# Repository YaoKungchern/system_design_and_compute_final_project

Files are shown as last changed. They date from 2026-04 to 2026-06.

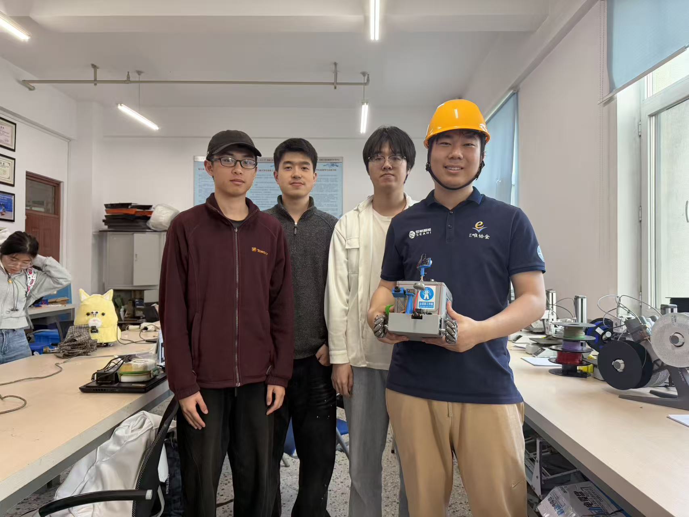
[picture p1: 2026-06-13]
docs/合照.jpg

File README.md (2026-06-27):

# System Design and Compute Final Project — Trace Rover

> 系统设计与计算课程期末项目：基于 STM32H723 的麦克纳姆轮巡逻小车（Trace Rover）下位机控制工程。

本仓库为课程期末项目的源代码与文档归档，核心是一个运行在 **STM32H723VGTx（Cortex‑M7）** 上的嵌入式控制系统，负责小车的电机驱动、PWM 输出、串口通信以及与上位机的交互。整体工程使用 **Keil MDK‑ARM（uVision 5）+ ARMCLANG V6.19** 开发，同时支持 **Embedded IDE (EIDE)** 环境。

---

## 目录结构总览
```shell
system_design_and_compute_final_project/
├── LICENSE                    # 项目开源协议（MIT）
├── README.md                  # 项目说明文档（本文件）
├── .gitignore                 # Git 忽略规则
├── control/                   # 下位机嵌入式控制工程（STM32H723）
│   └── Trace_Rover/           # Keil MDK-ARM 工程根目录
│       ├── .eide/             # Embedded IDE 配置文件（可选）
│       ├── Core/              # 用户核心代码（Inc 头文件 + Src 源码）
│       ├── Drivers/           # HAL 驱动与 CMSIS 头文件
│       │   ├── CMSIS/         # ARM CMSIS 核心与 STM32H7 设备支持包
│       │   └── STM32H7xx_HAL_Driver/ # ST 官方 HAL 库源码
│       ├── MDK-ARM/           # Keil 工程文件、编译产物与调试配置
│       ├── .mxproject         # STM32CubeMX 项目记录
│       └── .clang-format      # C/C++ 代码格式化规则
├── software/                  # 上位机控制软件（PyQt5 + Python 3.11）
│   └── Trace_Rover_GC/        # Qt Creator 工程根目录
│       ├── .qtcreator/        # Qt Creator 工程配置与 Python 虚拟环境
│       ├── main.py            # 程序入口
│       ├── main_widget.py     # 主界面逻辑（配合 main_widget.ui）
│       ├── control_widget.py  # 手动控制面板逻辑
│       ├── pid_widget.py      # PID 参数调参面板逻辑
│       ├── main_func.py       # 主要功能调度
│       ├── trace_rover_comm.py # 与下位机的串口通信协议实现
│       ├── navigation.py      # 导航与路径规划模块
│       ├── mission.py         # 任务编排与执行模块
│       ├── vision.py          # 视觉图像处理模块（图传/识别）
│       ├── control.py         # 控制指令生成模块
│       ├── pid.py             # 上位机 PID 控制器实现
│       ├── config.py          # 全局配置参数
│       ├── utils.py           # 通用工具函数
│       ├── main_widget.ui     # 主界面 UI 设计文件
│       ├── control_widget.ui  # 控制面板 UI 设计文件
│       └── pid_widget.ui      # PID 调参面板 UI 设计文件
├── electronics/               # 硬件工程（嘉立创 EDA）
│   └── ProPrj_TraceRover_2026-03-28.epro2 # 嘉立创工程文件（原理图 + PCB）
├── structure/                 # 机械结构文件（SolidWorks）
│   ├── （模型装配体）.SLDASM   # 整车总装配体
│   ├── 上层装配1.SLDASM       # 上层板/传感器组件装配
│   ├── Board.step.STEP.SLDASM # 主板/PCB 安装支架装配
│   ├── Enter.step.STEP.SLDASM # 外壳/舱门部件装配
│   ├── Next.step.STEP.SLDASM  # 外壳/舱门部件装配
│   ├── J1/J3/J6.step.STEP.SLDASM # 连接器/接口部件装配
│   ├── ZDT_X28_L28Motor.STEP.SLDASM # 步进电机驱动板装配
│   ├── ZDT_X28_V1.2_PCB.step.STEP.SLDASM # 步进电机驱动板 PCB 装配
│   ├── 28_STEPPER_MOTOR.STEP.SLDPRT # 28 步进电机零件模型
│   ├── MC520编码器电机模型-升级款.step.SLDPRT # 带编码器的主驱动电机
│   ├── 80l/80r.SLDPRT         # 左右轮系零件
│   ├── 上层板绘制尝试.SLDPRT  # 上层板结构零件
│   ├── 底盘模型.SLDPRT        # 底盘结构零件
│   ├── 小车底盘壳.SLDPRT      # 底盘外壳零件
│   ├── 上下板连接铜柱.SLDPRT  # 连接件零件
│   ├── 支柱.SLDPRT            # 支撑零件
│   ├── PCB支柱.SLDPRT         # PCB 支撑零件
│   ├── 相机底座.SLDPRT        # 相机安装支架
│   ├── 相机柱.SLDPRT          # 相机支撑柱
│   ├── 相机柱80mm.SLDPRT      # 相机支撑柱（80mm）
│   ├── 电机延长轴.SLDPRT      # 传动零件
│   ├── 电机联轴器.SLDPRT      # 传动零件
│   ├── 滑环轴.SLDPRT          # 导电滑环轴
│   ├── 六角联轴器.step.SLDPRT # 联轴器零件
│   ├── 皮带1-1.SLDPRT         # 同步带零件
│   ├── 皮带线同步带-2.SLDPRT  # 同步带零件
│   ├── HTPA20S5M100_A_P6_35_a - 电机侧.SLDPRT # 同步带轮（电机侧）
│   ├── HTPA20S5M100_A_P6_35_a_导电滑环侧.SLDPRT # 同步带轮（滑环侧）
│   ├── ts-1145a-b-a_White.step.STEP.SLDPRT # 摄像头外壳
│   ├── 外壳终版.SLDPRT        # 最终版外壳外罩
│   ├── 电池.SLDPRT            # 电池盒模型
│   ├── 37电机支架.step.SLDPRT # 37 电机安装支架
│   ├── Sensor Ultrasónico.SLDPRT # 超声波传感器模型
│   ├── 图传发射模块.SLDPRT    # 图传发射模块外罩
│   ├── ZDT_X28_L28Motor.STEP  # 步进电机驱动板 STEP 模型
│   ├── ZDT_X28_V1.2.STEP.SLDPRT # 步进电机驱动板 PCB 模型
│   ├── WIRE_2.0.STEP.SLDPRT   # 线束模型
│   ├── SHIM_2.7x4x6.STEP.SLDPRT # 垫片模型
│   ├── Open CASCADE STEP translator 6.8 1.1.1.step.STEP.SLDPRT # 第三方 STEP 零件
│   ├── MT0522..FL.SLDPRT      # 法兰支架零件
│   ├── BREACKET.SLDPRT        # 通用支架零件
│   ├── PH2.0-WI-4P.step.STEP.SLDASM # PH2.0 连接器装配（4P）
│   ├── PH2.0-WI-8P.step.STEP.SLDASM # PH2.0 连接器装配（8P）
│   ├── PH2.0-WI-4P-0.step.STEP.SLDPRT # PH2.0 连接器单零件（4P）
│   ├── PH2.0-WI-8P-3.step.STEP.SLDPRT # PH2.0 连接器单零件（8P）
│   ├── PH2.0-WI--1.step.STEP.SLDPRT # PH2.0 连接器外壳
│   ├── PH2.0-WI-.step.STEP.SLDPRT # PH2.0 连接器锁片
│   ├── 6308926832.step.STEP.SLDASM # 采购件/标准件装配
│   └── 6308926992.step.STEP.SLDASM # 采购件/标准件装配
└── docs/                      # 项目文档与多媒体文件
    ├── 项目开题报告.pptx      # 开题答辩 PPT
    ├── 项目开题报告.pdf       # 开题报告 PDF
    ├── 项目结题报告.pptx      # 结题答辩 PPT
    ├── 项目结题报告.pdf       # 结题报告 PDF
    ├── 通信数据帧格式.xlsx    # 上下位机通信协议定义
    ├── 讲解视频.mp4           # 系统讲解视频
    ├── 宣传视频.mp4           # 项目宣传视频
    └── 合照.jpg               # 团队/实物合照
```

---

### 1. `docs/` — 项目文档与多媒体

`docs/` 目录是课程提交的核心资料，汇集了从开题到结题的全流程文档与展示素材，按用途可分为四组。

| 组别 | 文件 | 内容与用途 |
| --- | --- | --- |
| **开题阶段** | `项目开题报告.pptx`
`项目开题报告.pdf` | 项目立项资料：选题背景、系统需求分析、总体方案设计（机械结构 / 硬件电路 / 软件架构 / 通信协议）、预期功能与性能指标、时间节点规划。答辩用 PPT 及 PDF 定稿版本。 |
| **结题阶段** | `项目结题报告.pptx`
`项目结题报告.pdf` | 项目结项资料：系统实现细节、关键算法（电机 PID、路径规划、上位机交互）、测试与实验结果、性能分析、问题与改进总结。答辩用 PPT 及 PDF 定稿版本。 |
| **通信协议** | `通信数据帧格式.xlsx` | **上位机‑下位机通信的数据帧规范文档**。定义了帧头、设备地址、功能码、数据域、校验和（异或校验）、帧尾等字段的字节排列、大小端、单位与取值范围；同时列出了小车运行、停止、速度调节、转向、状态回传等命令码。是两端软件联调的契约文件。 |
| **展示素材** | `讲解视频.mp4` | 功能讲解视频：对系统整体方案、硬件组成、软件流程、现场演示进行讲解，用于课程答辩与成果展示。 |
| | `宣传视频.mp4` | 项目宣传视频：展示小车外观、运行效果与亮点功能，用于课程作业展示、宣传或评奖材料。 |
| | `合照.jpg` | 项目团队合照 / 小车实物合照，作为结题资料存档。 |

> **重点提示**：
> - `通信数据帧格式.xlsx` 是软件开发人员的首要参考文档，定义了上位机与下位机之间的字节级通信契约。
> - `项目结题报告.pdf` / `.pptx` 是对整个项目架构、实现与测试最完整的文字化总结，建议作为阅读代码前的前置资料。
> - 两份视频分别面向"功能讲解"与"成果宣传"两种场景，按需观看。

---

## 各文件夹及文件功能详解

### 2. `control/Trace_Rover/` — 下位机控制工程（STM32H723）

这是项目的核心工程目录，对应一辆名为 **Trace Rover** 的履带式巡逻小车的下位机固件。

| 子目录/文件 | 功能说明 |
| --- | --- |
| `.eide/` | Embedded IDE（VS Code 插件）的工程配置：
- `eide.yml`：EIDE 工程主配置
- `env.ini`：构建环境变量
- `files.options.yml`：文件级编译选项
- `trace_rover.st.option.bytes.ini`：STM32 选项字节配置 |
| `.cmsis/` | CMSIS 设备模板，包含 ARM Cortex‑A/M 系列的启动代码、链接脚本与内核头文件，用于多芯片支持 |
| `Core/Inc/` | 用户头文件：`main.h`、`gpio.h`、`tim.h`、`usart.h`、`stm32h7xx_it.h`、`stm32h7xx_hal_conf.h` |
| `Core/Src/` | 用户源代码，详见下方小节 |
| `Drivers/CMSIS/` | ARM CMSIS 核心头文件（`core_cm7.h` 等）、编译器适配层，以及 STM32H7 设备寄存器定义（`stm32h723xx.h`） |
| `Drivers/STM32H7xx_HAL_Driver/` | ST 官方 HAL 库：`Inc/` 提供外设驱动头文件，`Src/` 为对应实现（GPIO、UART、TIM、DMA、RCC、PWR、FLASH、I2C、EXTI 等） |
| `MDK-ARM/` | Keil uVision5 工程：
- `Trace_Rover.uvprojx` / `.uvoptx`：工程与选项文件
- `DebugConfig/*.dbgconf`：调试配置
- `RTE/_Trace_Rover/RTE_Components.h`：运行时组件头文件
- `Trace_Rover/`：编译产物（`.axf`、`.hex`、`.map`、`.htm` 等） |
| `.mxproject` | STM32CubeMX 生成/记录文件，表明工程由 CubeMX 初始化后进行二次开发 |
| `.clang-format` | 统一的代码风格配置文件，便于 CLion / VS Code / Keil 等 IDE 自动格式化 |

> **值得注意的编译产物线索**：从 `MDK-ARM/Trace_Rover/` 下的 `.o` 目标文件可以反向推断出工程中实际存在但未在 `Core/Src/` 目录显式出现的业务模块——`actuator.o`、`comm.o`、`fsm.o`、`filter.o`、`tasks.o`、`time_slice.o`、`ultrasonic.o`、`pid.o`、`coordinate2d.o`、`mecanum.o`、`fifo.o`。这些模块分别实现了执行器控制、通信协议、有限状态机（FSM）、滤波、任务调度、时间片轮转、超声波采集、PID、坐标变换、麦轮运动学解算等核心功能，是整个下位机控制的"真正大脑"。

#### `Core/Src/` 源码解读

| 文件 | 功能 |
| --- | --- |
| `main.c` | **程序入口**。初始化 HAL、配置系统时钟（HSE + PLL，主频 550 MHz 级别）、初始化 GPIO / TIM1/2/3/4/5/8/15 / USART1/2/3，然后调用 `tasks_init()` 并在主循环中执行 `tasks_run()` 进行调度。 |
| `gpio.c` | GPIO 初始化：LED、按键、电机方向控制引脚等 |
| `tim.c` | 定时器初始化：TIM1/TIM8 用于 PWM 驱动电机，TIM2/TIM3/TIM4/TIM5 用于输入捕获或编码器测速，TIM15 用于周期性中断（任务调度/心跳） |
| `usart.c` | 串口初始化：USART1/2/3，分别对应上位机通信、调试串口、外部传感器/模块通信 |
| `stm32h7xx_it.c` | 中断服务例程（HardFault、SysTick、UART、TIM 等） |
| `stm32h7xx_hal_msp.c` | HAL 底层初始化（GPIO 复用、时钟使能、DMA 配置） |
| `system_stm32h7xx.c` | 系统启动文件与向量表相关辅助函数 |

---

### 3. `software/Trace_Rover_GC/` — 上位机控制软件（PySide6 + Python 3.11）

这是运行在 PC 端的上位机图形化控制程序，使用 **Qt Creator** 作为 UI 设计工具，运行在 **Python 3.11** 虚拟环境中。主要功能包括：手动遥控小车、下发运动指令、实时回传并显示小车状态数据、PID 参数在线调参、视觉图像（图传画面）显示与处理、以及按任务序列自动巡航。

#### 核心 Python 源文件

| 文件 | 功能 |
| --- | --- |
| `main.py` | **程序入口**。初始化 QApplication、加载主窗口 `main_widget`、启动事件循环。 |
| `main_widget.py` | 主界面逻辑实现。整合串口状态显示、连接按钮、手动/自动模式切换、小车状态面板、图像显示区、日志窗口等。配合 `main_widget.ui` 共同描述界面布局。 |
| `control_widget.py` | **手动控制面板逻辑**。提供开环、速度闭环与位置闭环再不同坐标系下控制等操作入口，通过 `control.py` 与 `trace_rover_comm.py` 下发指令。 |
| `pid_widget.py` | **PID 参数调参面板**。提供 P/I/D 三系数的输入框、读写按钮、载入与保存参数按钮，通过串口与下位机同步参数。 |
| `main_func.py` | **主功能调度器**。整合 `navigation`、`mission`、`vision`、`control`、`pid` 等模块，在主循环中按帧处理：解析传感器数据 → 更新状态 → 生成控制量 → 下发下位机。 |
| `trace_rover_comm.py` | **串口通信协议核心**。按照 `docs/通信数据帧格式.xlsx` 中定义的字节顺序、校验规则，实现：- 帧打包（添加帧头、功能码、CRC/异或校验、帧尾）- 帧解包（校验、拆分字段、以事件回调方式通知上层）- 指令码枚举（运行、导航、PID 读写、心跳、版本查询等） |
| `navigation.py` | **导航可视化模块**。读取下位机返回的导航数据，实时绘制小车位置、速度、障碍物等信息。 |
| `mission.py` | **任务编排与执行模块**。以航点表或时间线形式组织一次任务："到达 A 点 → 旋转摄像头 → 等待 2 秒 → 返回起点"。由 `main_func.py` 按状态机推进。 |
| `vision.py` | **视觉图像处理模块**。读取 USB 摄像头或图传接收机画面，进行简单处理（去畸变、裁剪、在画面上叠加坐标/速度文字），并把图像渲染到 `main_widget` 的显示区，并可以接入YOLO26模型进行目标检测、ArUco标记识别修正导航坐标。 |
| `control.py` | **控制指令生成模块**。把上位机用户输入或导航模块给出的目标速度/角速度/坐标，换算为符合通信协议格式的指令帧，并调用 `trace_rover_comm.py` 下发。 |
| `pid.py` | **上位机 PID 调参实现**。读取 `pid_widget.py` 中的 P/I/D 参数，通过串口与下位机同步参数。 |
| `config.py` | **全局配置**。串口号、波特率、小车物理参数（轮径、轮距、最大速度、加速度限制）、导航坐标原点、摄像头分辨率与设备号等。 |
| `utils.py` | **通用工具函数**。数据类型转换（int↔bytes、大小端）、坐标变换、CRC 计算、日志工具、时间戳生成。 |

#### UI 设计文件（Qt Designer / Qt Creator）

| 文件 | 说明 |
| --- | --- |
| `main_widget.ui` | 主窗口布局：顶部菜单栏、左侧控制按钮区、中央图像显示区、右侧状态面板、底部日志区。 |
| `control_widget.ui` | 手动控制面板的独立布局文件；以子窗口或 tab 页形式嵌入主界面。 |
| `pid_widget.ui` | PID 调参面板布局：P/I/D 参数输入框、目标/当前值显示、曲线画布（使用 QCustomPlot 或 Matplotlib）。 |

#### 虚拟环境与配置

| 目录/文件 | 说明 |
| --- | --- |
| `.qtcreator/Python_3_11_7venv/` | Qt Creator 自动创建的 Python 3.11 虚拟环境，内含 `pip`、`setuptools`、`pkg_resources`、`distutils` 等基础包；项目运行时需先在此环境中安装 `PySide6`、`pyserial`、`numpy`、`opencv-python`、`matplotlib` 等依赖。 |

> **运行方式**：在 Qt Creator 中打开工程根目录（或直接在命令行 `python main.py`），选择正确的串口并点击连接，即可通过界面控制小车运动、观察图传画面、调参或触发自动任务。

---

### 4. `electronics/` — 硬件工程（嘉立创 EDA）

`electronics/` 目录中包含小车的完整硬件设计工程，使用国产 EDA 工具 **嘉立创 EDA（LCEDA / EasyEDA Pro）** 设计，文件格式为 `.epro2`。

| 文件 | 功能说明 |
| --- | --- |
| `ProPrj_TraceRover_2026-03-28.epro2` | **嘉立创工程文件**（一个文件即包含原理图 + PCB 叠层设计）。工程名为 "TraceRover"，创建/最后修改日期为 2026‑03‑28。通常内部包括：① **主控板**（STM32H723VGTx 最小系统 + USB 转串口 + 电源输入）；② **电机驱动通道**（PWM/方向/使能信号引出到大电流 H桥）；③ **传感器接口**（编码器正交信号、超声波 IO、IMU I2C/SPI）；④ **通信接口**（USART1 连上位机、USART2 调试、USART3 外接）；⑤ **电源管理**（从电池降压到 5V / 3V3，兼顾电机与传感器）；⑥ **预留拓展**（图传模块、舵机云台、摄像头接口）。 |

> **使用方式**：在嘉立创 EDA 客户端中直接双击 `.epro2` 打开；也可通过"嘉立创下单助手"直接导出 Gerber / BOM / 坐标文件进行 PCB 打样。如需查看 PDF 版原理图或装配图，可在嘉立创 EDA 中导出。

---

### 5. `structure/` — 机械结构（SolidWorks）

`structure/` 目录中集中存放 **SolidWorks** 的零件与装配体文件，对应一辆完整的履带式小车。按照"**结构件 → 传动件 → 连接件 → 外购件/标准件 → 总装配**"的思路，可以将文件分为以下类别：

#### ① 总装配与子装配（`.SLDASM`）

| 文件 | 说明 |
| --- | --- |
| `（模型装配体）.SLDASM` | **整车总装配**，集成底盘、上层板、电机、履带、相机、电池、PCB 支架等所有零件。 |
| `上层装配1.SLDASM` | 上层板及传感器组件的装配（相机支架、铜柱、图传模块等）。 |
| `Board.step.STEP.SLDASM` | PCB / 主控板安装支架的装配。 |
| `Enter.step.STEP.SLDASM` / `Next.step.STEP.SLDASM` | 外壳相关的子装配体，用于覆盖车身并预留接口。 |
| `J1/J3/J6.step.STEP.SLDASM` | 不同规格连接器在整机中的装配单元。 |
| `ZDT_X28_L28Motor.STEP.SLDASM` | 28 步进电机驱动板的装配体。 |
| `ZDT_X28_V1.2_PCB.step.STEP.SLDASM` | 步进电机驱动板 PCB 的装配体版本。 |
| `6308926832.step.STEP.SLDASM` / `6308926992.step.STEP.SLDASM` | 外购件/标准件（编号来自供应商或在线 3D 零件库）的 STEP 装配体。 |
| `PH2.0-WI-4P.step.STEP.SLDASM` / `PH2.0-WI-8P.step.STEP.SLDASM` | PH2.0 连接器（4 针/8 针）的完整装配。 |

#### ② 结构件与外壳（`.SLDPRT`）

| 文件 | 说明 |
| --- | --- |
| `上层板绘制尝试.SLDPRT` | 上层板原始建模，用于搭载主控板和传感器。 |
| `底盘模型.SLDPRT` / `小车底盘壳.SLDPRT` | 底盘基础结构，用于承载电机、电池、驱动器。 |
| `外壳终版.SLDPRT` | 最终定型的外壳外罩，保护内部结构。 |
| `电池.SLDPRT` | 电池盒模型。 |
| `支柱.SLDPRT` / `上下板连接铜柱.SLDPRT`（含若干副本）| 上下层连接支柱系列（不同长度/接口）。 |
| `PCB支柱.SLDPRT` | PCB 专用安装支柱。 |
| `BREACKET.SLDPRT` | 通用小型支架。 |
| `MT0522..FL.SLDPRT` | 另一种法兰类支架零件。 |

#### ③ 相机 / 图传 / 传感器件（`.SLDPRT`）

| 文件 | 说明 |
| --- | --- |
| `相机底座.SLDPRT` / `相机柱.SLDPRT` / `相机柱80mm.SLDPRT` | 相机安装支架系列（不同高度/角度）。 |
| `图传发射模块.SLDPRT` | 图传发射模块外壳/安装件。 |
| `ts-1145a-b-a_White.step.STEP.SLDPRT` | 配套的摄像头外壳（白色，常见 3D 打印件）。 |
| `Sensor Ultrasónico.SLDPRT` | 超声波传感器（HC‑SR04 等）模型。 |

#### ④ 电机 / 传动件（`.SLDPRT`）

| 文件 | 说明 |
| --- | --- |
| `28_STEPPER_MOTOR.STEP.SLDPRT` | 28 步进电机零件。 |
| `MC520编码器电机模型-升级款.step.SLDPRT` | **主驱动电机**（带编码器），用于左右履带。 |
| `37电机支架.step.STEP.SLDPRT` | 37 直流减速电机安装支架。 |
| `电机延长轴.SLDPRT` / `电机联轴器.SLDPRT` | 电机延长轴与联轴器。 |
| `滑环轴.SLDPRT` | **导电滑环** 安装轴，解决旋转部件的供电/信号走线。 |
| `六角联轴器.step.SLDPRT` | 六角联轴器零件。 |
| `皮带1-1.SLDPRT` / `皮带线同步带-2.SLDPRT` | 同步带零件（不同长度/齿距）。 |
| `HTPA20S5M100_A_P6_35_a - 电机侧.SLDPRT` | 电机侧同步带轮。 |
| `HTPA20S5M100_A_P6_35_a_导电滑环侧.SLDPRT` | 滑环侧同步带轮。 |
| `ZDT_X28_L28Motor.STEP` / `ZDT_X28_V1.2.STEP.SLDPRT` | 步进电机驱动板的原始 STEP 零件与 SolidWorks 零件。 |

#### ⑤ 轮系与行走部分（`.SLDPRT`）

| 文件 | 说明 |
| --- | --- |
| `80l.SLDPRT` / `80r.SLDPRT` / `80l.2.SLDPRT` / `80r.2.SLDPRT` | **左右轮系**零件的 1 版与 2 版迭代。 |
| `SHIM_2.7x4x6.STEP.SLDPRT` | 调整间隙用垫片。 |

#### ⑥ 连接器与线束（`.SLDPRT`）

| 文件 | 说明 |
| --- | --- |
| `PH2.0-WI-4P-0.step.STEP.SLDPRT` / `PH2.0-WI-8P-3.step.STEP.SLDPRT` | PH2.0 连接器（4P/8P）的单零件模型。 |
| `PH2.0-WI-____-1.step.STEP.SLDPRT` / `PH2.0-WI-____.step.STEP.SLDPRT` | PH2.0 连接器外壳/锁片（占位型号）。 |
| `WIRE_2.0.STEP.SLDPRT` | 2.0 mm 线束模型。 |

#### ⑦ 导入的第三方 STEP 零件

| 文件 | 说明 |
| --- | --- |
| `Open CASCADE STEP translator 6.8 1.1.1.step.STEP.SLDPRT` | 经 Open CASCADE 工具从外部 STEP 转换后导入的零件。 |

> **使用建议**：先用 SolidWorks 打开 `（模型装配体）.SLDASM` 查看整车装配关系；之后可按装配树逐层查看各零件；如要修改，建议以 `.SLDPRT` 为单位在零件模式下编辑，改动较大时注意配合 `electronics/` 中的 PCB 工程重新验证安装孔与连接器位置。

---

## 软件架构概览
```shell
┌─────────────────────────────────────────────┐
│ 上位机 (PC / software/Trace_Rover_GC)        │
│ ┌──────────────────────────────────────┐    │
│ │ main_widget + control_widget         │    │ ← 图形化 UI
│ │ (PySide6: 手动控制 / PID 调参 / 图传)  │    │
│ └──────────────┬────────────────────────┘    │
│                │                             │
│ ┌──────────────▼────────────────────────┐    │
│ │ control.py / pid.py / navigation.py   │    │
│ │ mission.py / vision.py                │    │
│ └──────────────┬────────────────────────┘    │
│                │                             │
│ ┌──────────────▼────────────────────────┐    │
│ │ trace_rover_comm.py (协议打包/解包)    │    │
│ └──────────────┬────────────────────────┘    │
└────────────────┼─────────────────────────────┘
                 │
                 │ 串口 (UART, 波特率详见 config.py)
                 │ 协议格式：docs/通信数据帧格式.xlsx
                 ▼
┌─────────────────────────────────────────────┐
│ STM32H723VGTx (Cortex-M7, 550MHz)           │
│ ┌────────────────────────────────────────┐  │
│ │ tasks_run() 调度循环                    │  │
│ │ ├─ comm_task()  ─► 帧解析/打包          │  │
│ │ ├─ actuator_task() ─► 电机 PWM / 舵机   │  │
│ │ ├─ sense_task() ─► 编码器/超声波采集     │  │
│ │ ├─ fsm_task() ─► 有限状态机             │  │
│ │ ├─ pid_task() ─► 速度环/位置环 PID      │  │
│ │ └─ report_task() ─► 状态回传上位机      │  │
│ └────────────────────────────────────────┘  │
│ HAL Driver (TIM / UART / GPIO / DMA)        │
└─────────────────────────────────────────────┘
                 │
                 ▼
┌─────────────────────────────────────────────┐
│ 左右电机 │ 编码器 │ 传感器/图传               │
└─────────────────────────────────────────────┘
```
---

## 构建与烧录

### 下位机（`control/Trace_Rover/`）

1. **使用 Keil MDK‑ARM**：
   - 打开 `control/Trace_Rover/MDK-ARM/Trace_Rover.uvprojx`
   - 确认已安装 `Keil.STM32H7xx_DFP.4.0.0` 支持包
   - 选择目标 `Trace_Rover`，执行 **Build** 生成 `Trace_Rover.hex`
   - 使用 ST‑Link / J‑Link 烧录到 STM32H723VGTx

2. **使用 Embedded IDE (EIDE)**：
   - 在 VS Code 中安装 EIDE 插件
   - 导入 `control/Trace_Rover/.eide/eide.yml`
   - 选择工具链并编译/下载

### 上位机（`software/Trace_Rover_GC/`）

1. 创建并激活 Python 3.11 虚拟环境（或复用 `.qtcreator/Python_3_11_7venv`）
2. 安装依赖：`pip install PyQt5 pyserial numpy opencv-python matplotlib`
3. 在项目根目录执行 `python main.py`，或在 Qt Creator 中直接运行

### 通信协议参考

详见 `docs/通信数据帧格式.xlsx`，其中定义了上下位机之间所有的帧格式与指令码。

---

## 许可协议

本项目采用 **MIT License**，详见根目录 `LICENSE` 文件。

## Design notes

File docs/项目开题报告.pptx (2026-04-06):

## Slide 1

Mecanum-wheeled Autonomous Tracking Robot
Thesis Proposal

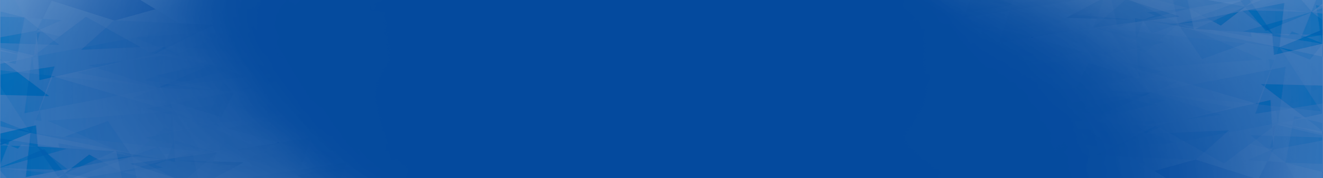
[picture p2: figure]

项目组长

姚康晨

项目成员

金振宇 王明睿 赵禺赫 罗子轩

汇报日期

2026.3.14

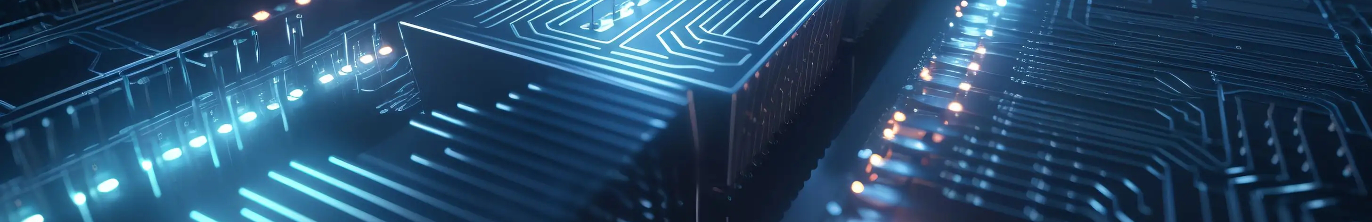
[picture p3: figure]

Trace Rover Team

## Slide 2

1. Project Background and Topic Selection
2. Structure
3. Control
4. Electronic
5. Vision
6. Software
7. Budget
8. Summary

Contract

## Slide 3

Project Background and Topic Selection

Market Background & Industry Needs

The demand for agile maneuvering has surged, while traditional chassis have encountered bottlenecks.

Macro Demand: In complex scenarios such as intelligent manufacturing, warehouse logistics, and disaster area reconnaissance, robots need to shuttle and track targets with high precision in narrow, unstructured spaces.
Existing problems: Traditional differential-drive chassis suffer from large turning radius and limited maneuverability. Existing omnidirectional Mecanum-wheel chassis improve mobility, but severe vibration and slippage often occur in practice due to rigid contact.
Industry Needs: There is an urgent need for a mobile platform with both extreme maneuverability and high all-terrain stability to serve as a reliable carrier for visual tracking and robotic arm operation.

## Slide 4

Project Background and Topic Selection

Literature Review & Technical Pain Points

Technical Pain Points
Chassis Vibration and Lack of Suspension: Intermittent contact of Mecanum wheel rollers causes periodic vibration, and systems without independent suspension lose grip on uneven roads (Ref. 1, 2).
Nonlinear Slip and Trajectory Drift: Skidding makes ideal kinematic matrices ineffective for accurate dead reckoning, and traditional single closed-loop PID easily leads to trajectory deviation in high-speed response (Ref. 3, 4).
Separation of Computing Power and Control: Fragmented "upper computer + lower controller" solutions lack bottom-level high-density integration, resulting in system delay between sensor fusion and motor response (Ref. 5).

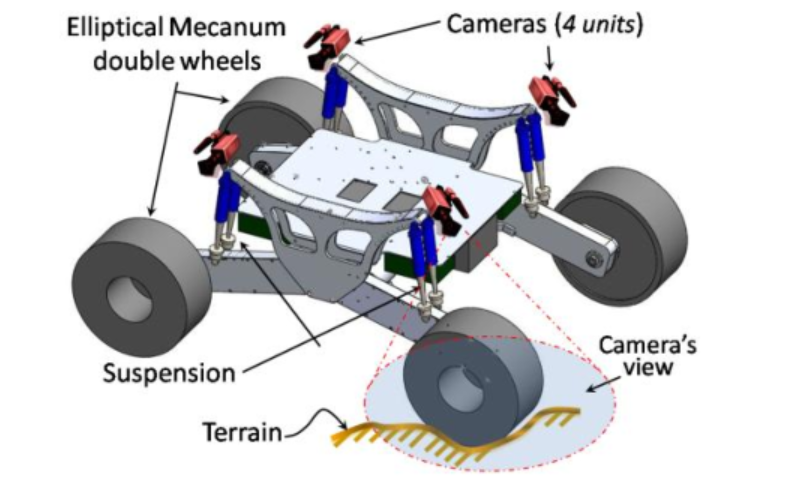
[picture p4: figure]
图示 AI 生成的内容可能不正确。

Reference

1. Oh, S. et al. (2021). "Vibration Reduction Control of Omnidirectional Mobile Robot with Lift Mechanism." IEEE International Conference on Control, Automation and Systems (ICCAS).
2. Chen, Y. et al. (2024). "Systematic Review of Mecanum and Omni Wheel Technologies for Motor Impairments." MDPI Applied Sciences.
3. Wang, H. et al. (2019). "Trajectory tracking for omnidirectional mecanum robot with longitudinal slipping." MATEC Web of Conferences.
4. Li, X. et al. (2018). "Highly Maneuverable Ground Reconnaissance Robot Based on Machine Learning." IEEE International Conference on Robotics and Biomimetics (ROBIO).
5. Zhang, M. et al. (2020). "Design of Inspection Robot for Spherical Tank Based on Mecanum Wheel." IEEE International Conference on Mechatronics and Automation (ICMA).

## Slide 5

Project Background and Topic Selection

Our Work

We are not "assembling" a small car, but building a highly coupled complex robot system from scratch.

System Closed-Loop:

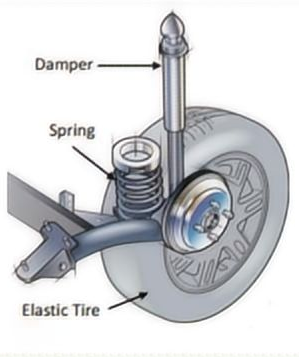
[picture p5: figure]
图示 AI 生成的内容可能不正确。

Mechanical Layer: Passive compliance for road adaptability via independent spring-damper suspension.

Hardware Layer: STM32H7 550MHz core for extreme space compression and ultra-low latency at the bottom board level.

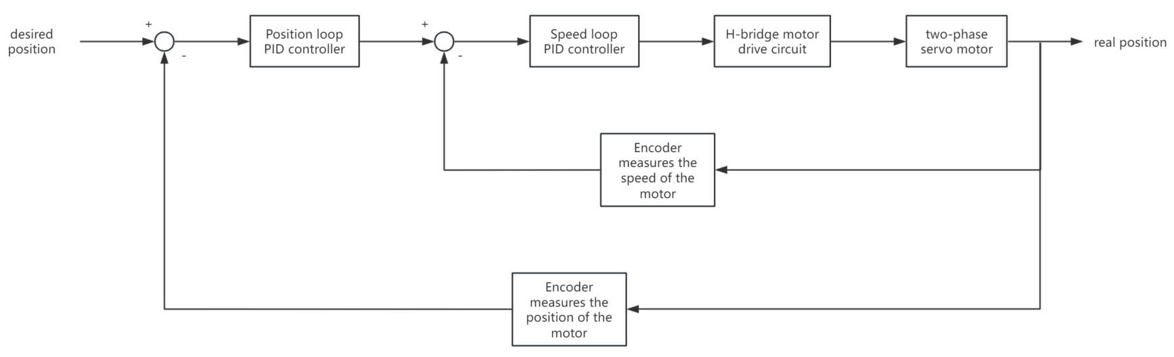
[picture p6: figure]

Control & Perception Layer: Cascade PID motor closed-loop + encoder dead reckoning + ultrasonic polar radar + YOLO visual tracking. Data of each subsystem is deeply fused at high frequency, with every part affecting the whole system.

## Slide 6

Project Background and Topic Selection

Objectives

Design and verify a highly stable omnidirectional mobile platform with a modular hierarchical architecture, low center of gravity, and a 2-DOF tracking gimbal.

Challenges

1. Parameter Matching and Tuning of Independent Suspension System in Narrow Space.
2. Multi-Motor Cooperative Closed-Loop and Dead Reckoning Error Handling of Mecanum Wheel Chassis.
3. Efficient Data Communication and Task Scheduling of Heterogeneous Software and Hardware Systems.

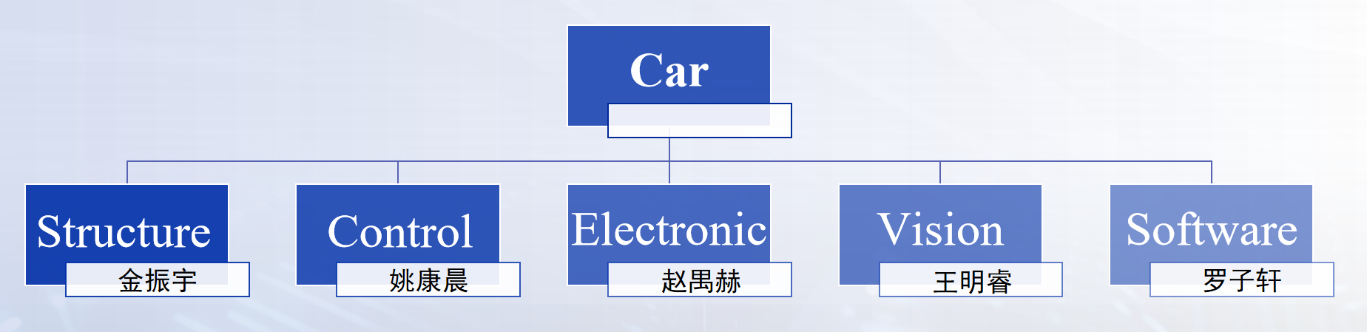
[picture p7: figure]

Task Division

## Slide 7

Structure

Core objective

Design and build a modular, high-stability, lightweight Mecanum-wheel mobile platform integrated with a 2-DOF gimbal to provide a reliable motion and execution carrier for tracking robots.

Overall Structural Design

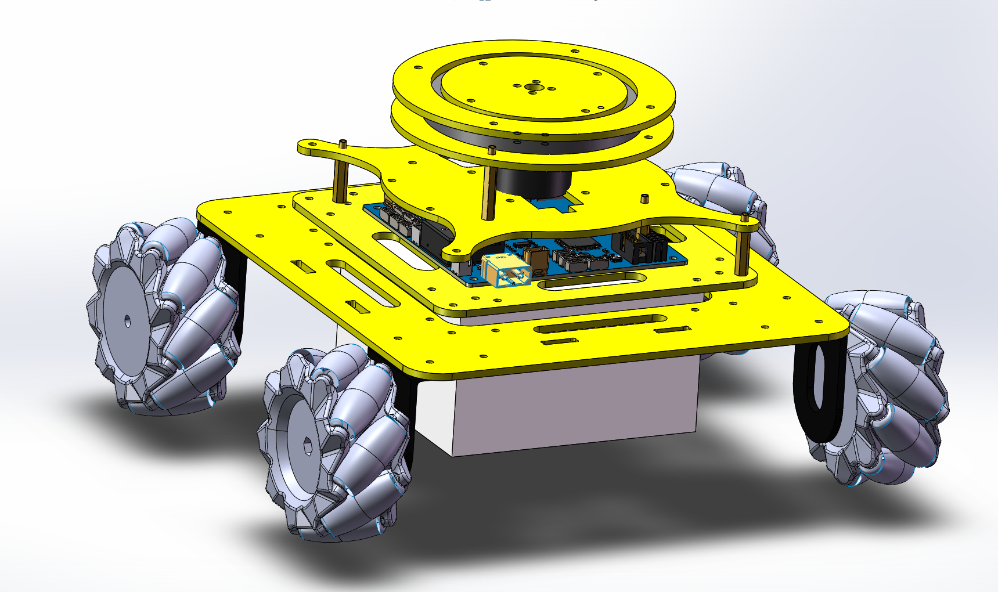
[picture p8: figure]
图片包含 桌子, 蛋糕, 乐高 AI 生成的内容可能不正确。

Modular Layered Architecture:
Segregates the chassis, control circuits, and tracking pan-tilt layers.
Ensures streamlined hardware debugging and scalable future expansion.
Optimized Spatial Layout:
Features a low center of gravity by placing batteries and heavy masses at the base, maximizing kinematic stability.
Ample upper-layer spacing ensures optimal heat dissipation for the control boards.

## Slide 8

Structure

Core Mechanical Modules

Omnidirectional Chassis

Adopt Mecanum wheels to achieve zero-radius turning and meet real-time tracking requirements.

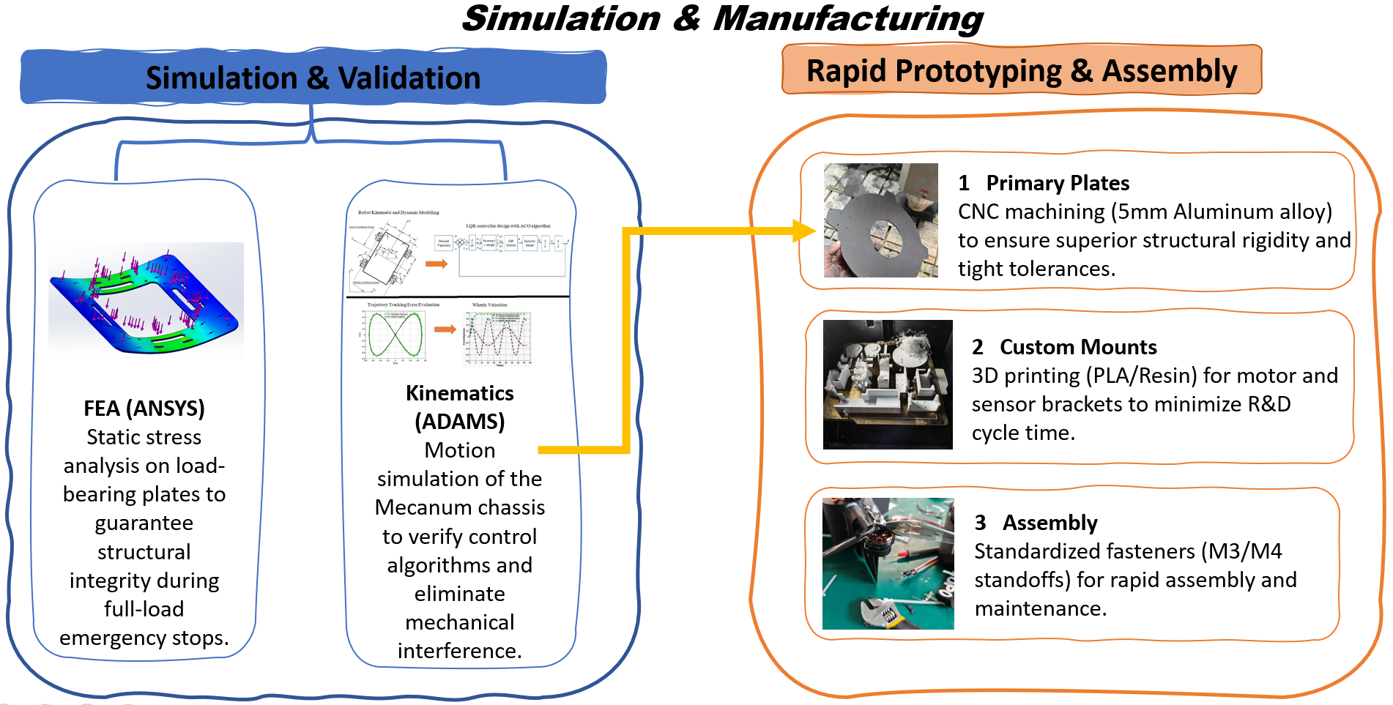
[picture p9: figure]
日程表 AI 生成的内容可能不正确。

Design independent spring-damper suspension for each wheel to solve the problem of simultaneous four-wheel contact and improve adaptability on uneven roads.

2-DOF Tracking Pan-Tilt

Lightweight disc structure, driven by dual servos, achieves fast and omnidirectional target locking.

Theoretical modeling and parameter optimization

Dynamic Modeling: We model the suspension as a quarter-car linear spring-damper system. The equation of motion is defined as:

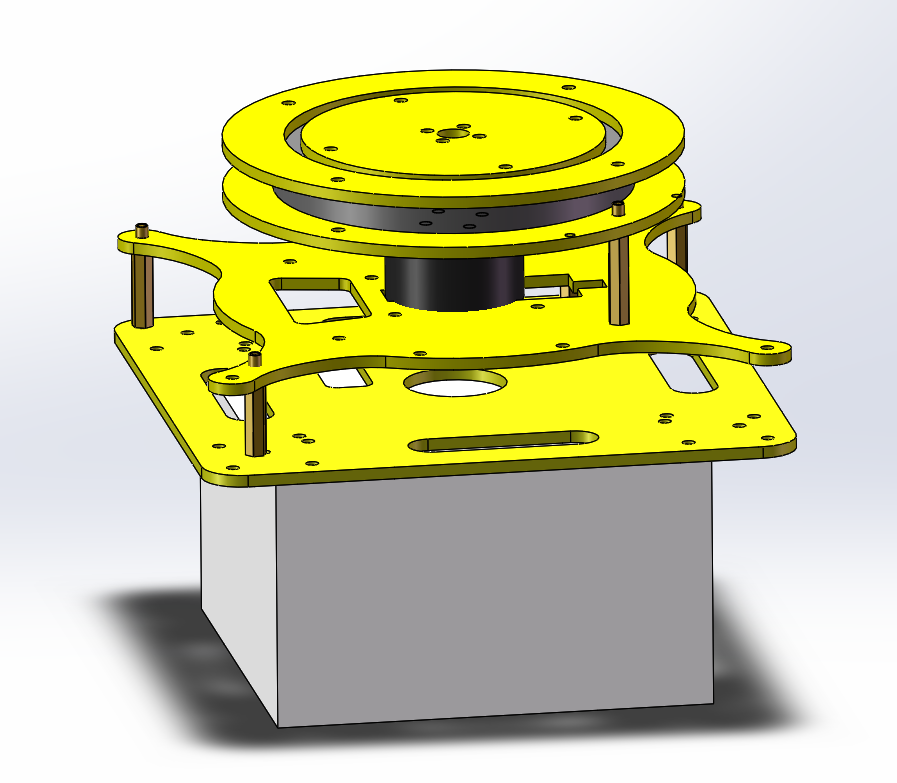
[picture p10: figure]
图片包含 游戏机, 桌子 AI 生成的内容可能不正确。

(Where m is quarter-mass, c is damping coefficient, k is spring stiffness).

Parameter Optimization: To prevent chassis resonance and optimize target-tracking stability, we calculate the natural frequency ωn and select springs to achieve an underdamped response:

Stiffness Selection: Based on a max payload of Wmax and desired deflection δmax, the required stiffness is determined by:

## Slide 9

Structure

Personal Task Assignment and Progress Schedule

Subtasks | Specific Content
1.1 Modeling Design | 3D modeling of chassis, suspension and gimbal (SolidWorks); material selection and preliminary layout
1.2 Simulation | Dynamic simulation of suspension system (e.g. ANSYS/Simulink); kinematic verification; parameter optimization
1.3 Manufacturing | CNC machining of main structural parts; 3D printing of brackets; procurement of standard parts; assembly and preliminary debugging

Progress Schedule

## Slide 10

Control

Motion control of Mecanum wheels

In order to control the movement of the AGV in the 3 degrees of freedom on the plane, we need its

inverse kinematics matrix

[s_1 s_2 s_3 s_4 ]=[1, 1, L+W1, −1, L+W1, −1, −(L+W)1, 1, −(L+W)][xyθ]

Through inverse kinematics, we can calculate the required speeds/positions for each motor by simply inputting the speed/displacement values in the Cartesian coordinate system.

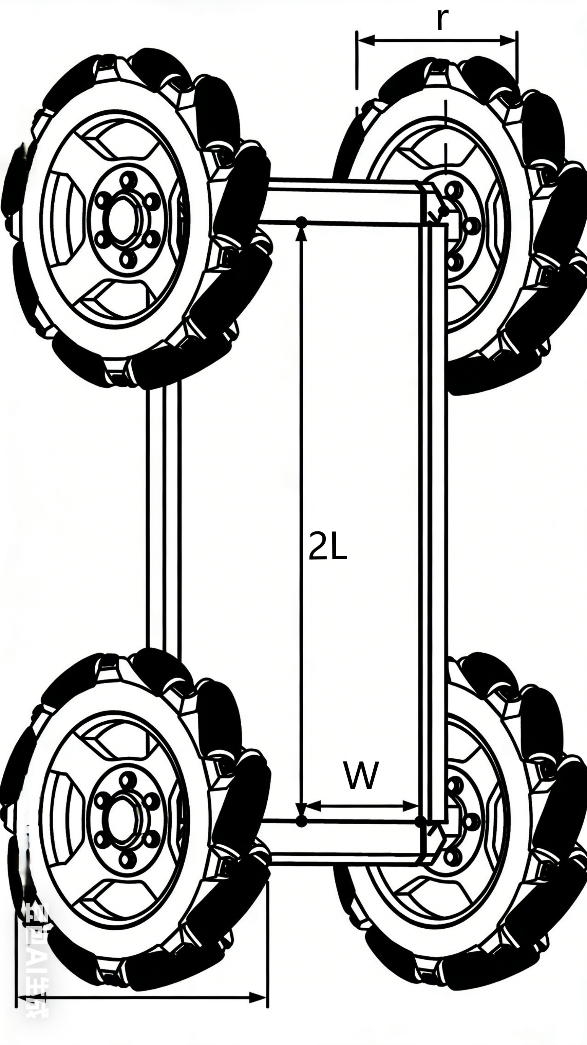
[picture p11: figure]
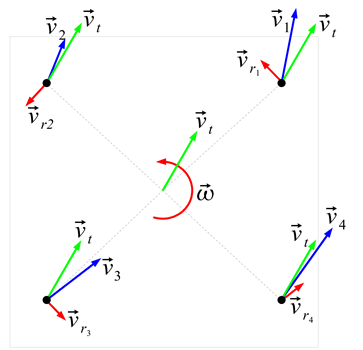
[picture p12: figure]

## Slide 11

Control

Inertial navigation system based on encoder

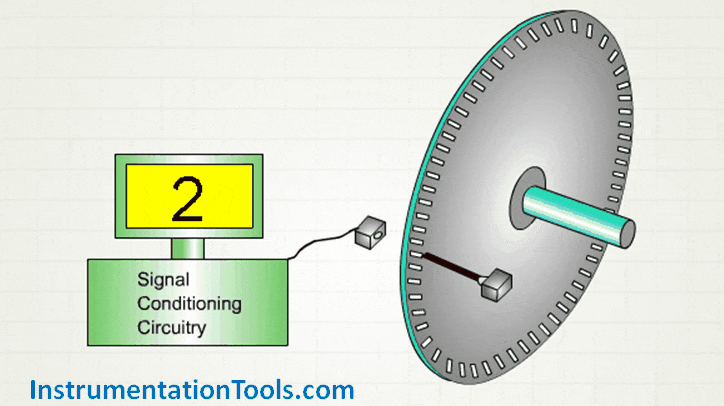
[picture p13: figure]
Encoder Working Animation

Encoders are used to translate rotary or linear motion into a digital signal. Usually this is for the purpose of monitoring or controlling motion parameters such as speed, rate, direction, distance or position.

After obtaining the rotation distances of the four wheels through the encoder, we can calculate the position and orientation of the AGV using the

forward kinematics matrix

[xyθ] =[1/4, 1/4, 1/4, 1/41/4, −1/4, −1/4, 1/41/(4(L+W)), −1/(4(L+W)), 1/(4(L+W)), −1/(4(L+W))] [s_1 s_2 s_3 s_4 ]

In this way, we can calculate the AGV's position and orientation in real time using the encoder data from the four wheels.

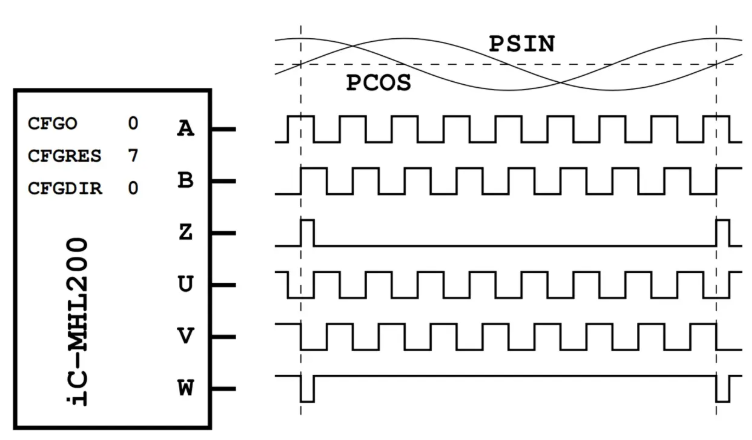
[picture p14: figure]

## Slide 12

Control

Closed-loop control of two-phase servo motors

The transfer function of the ideal two-phase servo motor system is

G(s)=(Ω_m (s))/(U_a (s))=(K_m)/(T_m s+1)

Although the ideal two-phase servo motor system is a simple first-order linear system, this system is prone to dynamic lag and parameter fluctuations due to the presence of inductance, inertia, and other parameters, and the position and speed variables are strongly coupled. A single-loop PID is unable to balance both dynamic response and positioning accuracy, so a cascade PID is designed. The block diagram is shown as follows.

After applying this controller, we can precisely adjust the position and speed of the motor. Combined with the previous kinematic analysis and inertial navigation system, we can freely control the position of the AGV.

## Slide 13

Control

An obstacle avoidance system composed of an ultrasonic sensor and a stepper motor

We use a stepper motor to drive the ultrasonic sensor installed on the conductive slip ring through a gear mechanism, causing it to rotate continuously. By combining the angle information from the stepper motor with the distance information input by the ultrasonic sensor, we can establish a polar coordinate system with the AGV as the origin to describe the information about the surrounding obstacles. Through the following algorithm, the obstacle information in the polar coordinate system can be converted into Cartesian coordinates.

{, x_(obstacle) =Rcos⁡(φ_(obstacle) ), y_(obstacle) =Rsin(φ_(obstacle) )

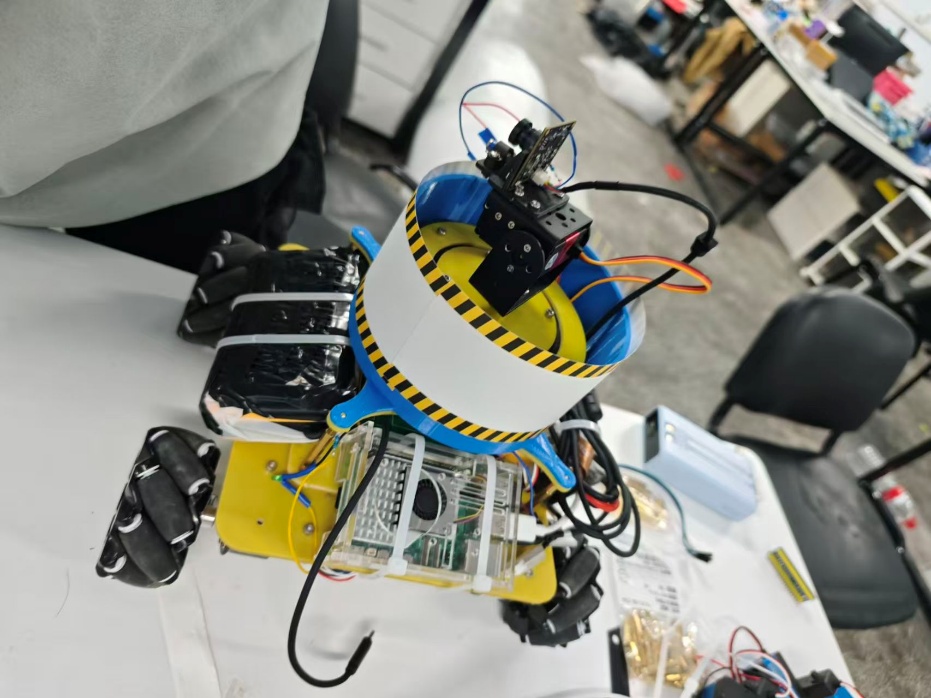
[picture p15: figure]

We can also utilize the inertial navigation system of the AGV to transform the obstacle information from the robot's coordinate system to the world coordinate system.

[x_(world) y_(world) ]=[cosθ_(robot) , −sinθ_(robot) sinθ_(robot) , cosθ_(robot) ][x_(obstacle) y_(obstacle) ]+[x_(robot) y_(robot) ]

The host computer records all the obstacle points detected by the AGV. We can even implement a simple SLAM system.

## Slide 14

Control

Personal Task Assignment and Progress Schedule

Subtasks | Specific Content
2.1 Module Programming | Write the programs for each module, such as the filter module, the controller module, and the navigation system module program.
2.2 Module Testing | Test each module independently to ensure that there are no issues with the modules during the later system development process.
2.3 MCU System Design | Reorganize the previous modules into tasks within the RTOS, maintaining a system design with high cohesion and low coupling.

Progress Schedule

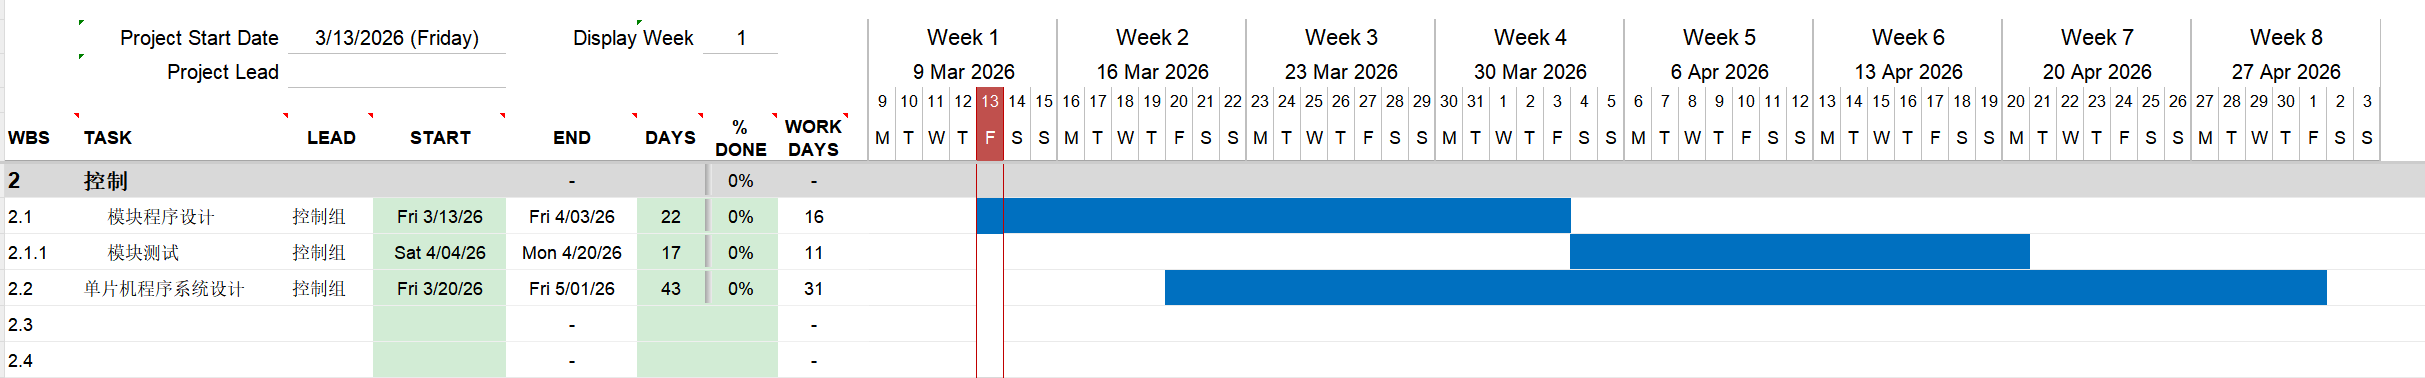
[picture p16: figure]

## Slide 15

Electronic

Core Objective

Design a highly integrated, low latency, and highly reliable electronic hardware platform for the autonomous tracking robot of the Mecanum wheel, achieving main control computation, multi-sensor fusion, and stable power supply, ensuring millisecond level response.

Integrated driver and control:
High-density integration of the main control MCU, power array, and peripheral interfaces on a single carrier board, compressing space and improving system compactness.

High performance core:
Adopting STM32H723VGT6 (550MHz), it meets the real-time requirements of Mecanum wheel kinematics calculation and multi-source data fusion.

Anti interference foundation:
Optimize power topology and communication bus, and build a robust hardware foundation.

Design Concept

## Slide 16

Electronic

Detailed plan and technical roadmap

Core: STM32H723VGT6

Peripheral interface: Reserved UART/I2C/SPI/CAN, compatible with multiple sensors.

Main control carrier board design

Input: Wide voltage DC-DC pre stabilization.

Output: Multiple independent LDOs provide power to MCU and sensors, with low noise.

Power module

Clock and reset: high-precision crystal oscillator, hardware watchdog.

Redundant design: Dual power hot backup to ensure operational stability.

Sensor circuit

PCB layout and testing

Signal conditioning: operational amplifier amplification, comparator shaping, optocoupler isolation.

Thermal distribution simulation: layout optimization of key components (MOSFET, MCU), heat dissipation via holes.

Test plan: signal integrity test, ripple test, power load pull test, vibration test.

360 ° ultrasonic radar: self-developed continuous rotating mechanism

Infrared locking array: high-frequency infrared transmitter/receiver

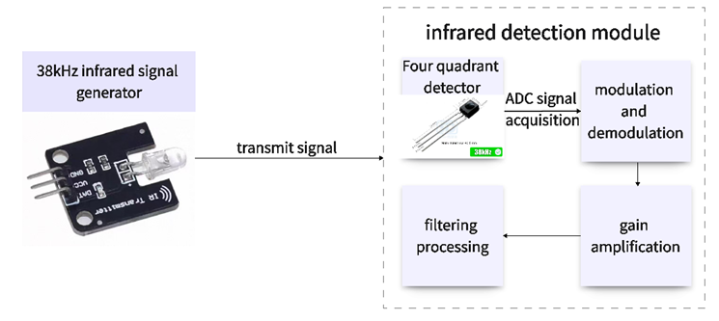
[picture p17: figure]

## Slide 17

Electronic

Innovation Points

Technical Challenge

- Heat dissipation management under high-density integration(Thermal distribution simulation and testing)

- Signal integrity assurance for 550MHz high-speed signals(Impedance control, crosstalk suppression)

- Hardware latency optimization for multi-sensor synchronization and data fusion

- The single board integrates the main control, power supply, and interface, significantly reducing the size and minimizing interconnect latency.

- Achieving 360 ° dynamic environment perception, and improving tracking robustness.

- Achieves precise target locking during high-speed motion.

- Ensure uninterrupted power supply under extreme working conditions and improve system reliability.

- Reliability of connectors and solder joints under vibration environment

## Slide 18

Electronic

Personal Task Assignment and Progress Schedule

Subtasks | Specific Content
3.1 Schematic Design | Design complete schematics for main carrier board using Altium Designer. Integrate STM32H723VGT6 MCU, power tree, sensor interfaces, and communication buses.
3.2 PCB Module Design | High-density PCB layout with impedance-controlled routing, thermal optimization, and power integrity design.
3.3 PCB Module Testing | Validate power rails (ripple <100mV), signal integrity, and communication protocols; perform thermal and vibration tests.
3.4 Carrier Board Design | Integrate PCB with motor and sensors; debug MCU–driver–sensor communication; optimize power design.

Progress Schedule

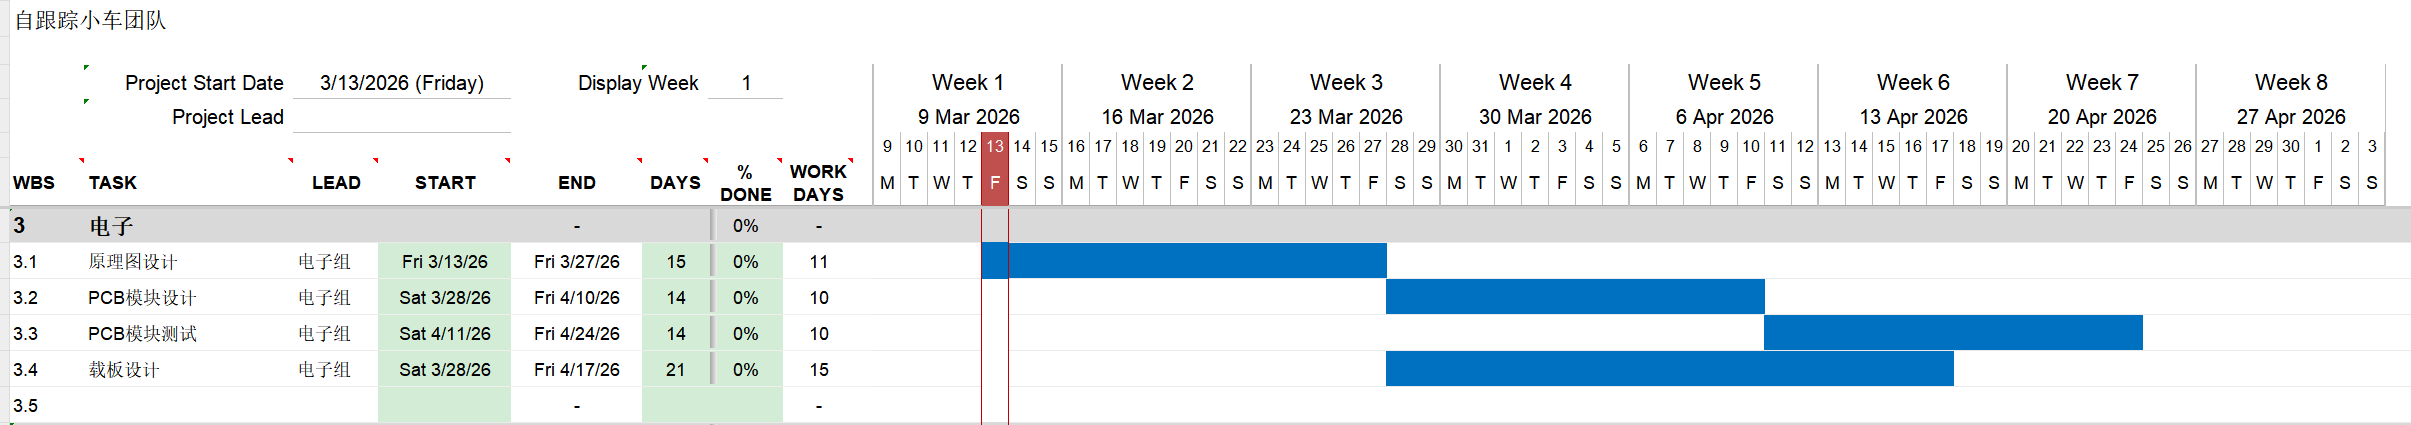
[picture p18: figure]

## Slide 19

VISION

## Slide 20

VISION

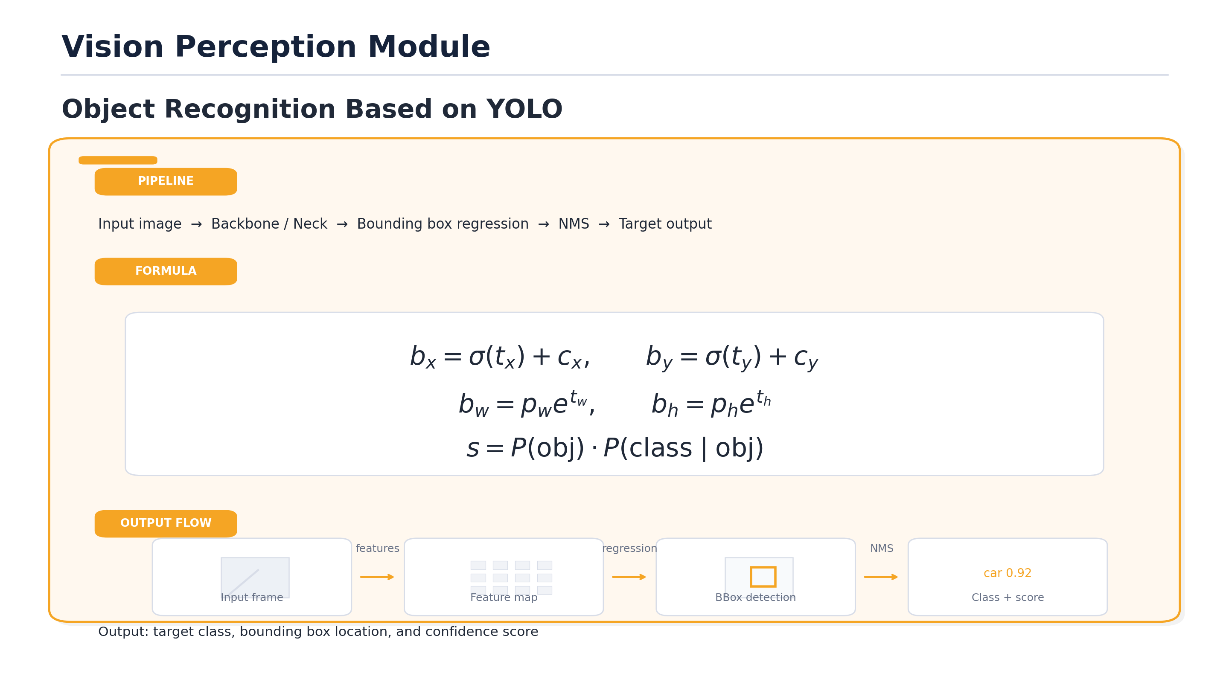
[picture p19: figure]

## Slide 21

VISION

Personal Task Assignment and Progress Schedule

Subtasks | Specific Content
4.1 Training Set Collection | Calibrate the onboard camera and record video data under diverse lighting and road scenarios; extract frames and manually annotate lane boundaries for threshold‑based detection and bounding boxes for YOLO training.
4.2 Model Training | Test each module independently to ensure that there are no issues with the modules during the later system development process.
4.3 Model Testing | Verify lane mask accuracy, center extraction, and lateral error under varied conditions while ensuring YOLO delivers correct bounding boxes and class scores with effective NMS; run both modules concurrently to assess real‑time performance and format final outputs for control systems.

Progress Schedule

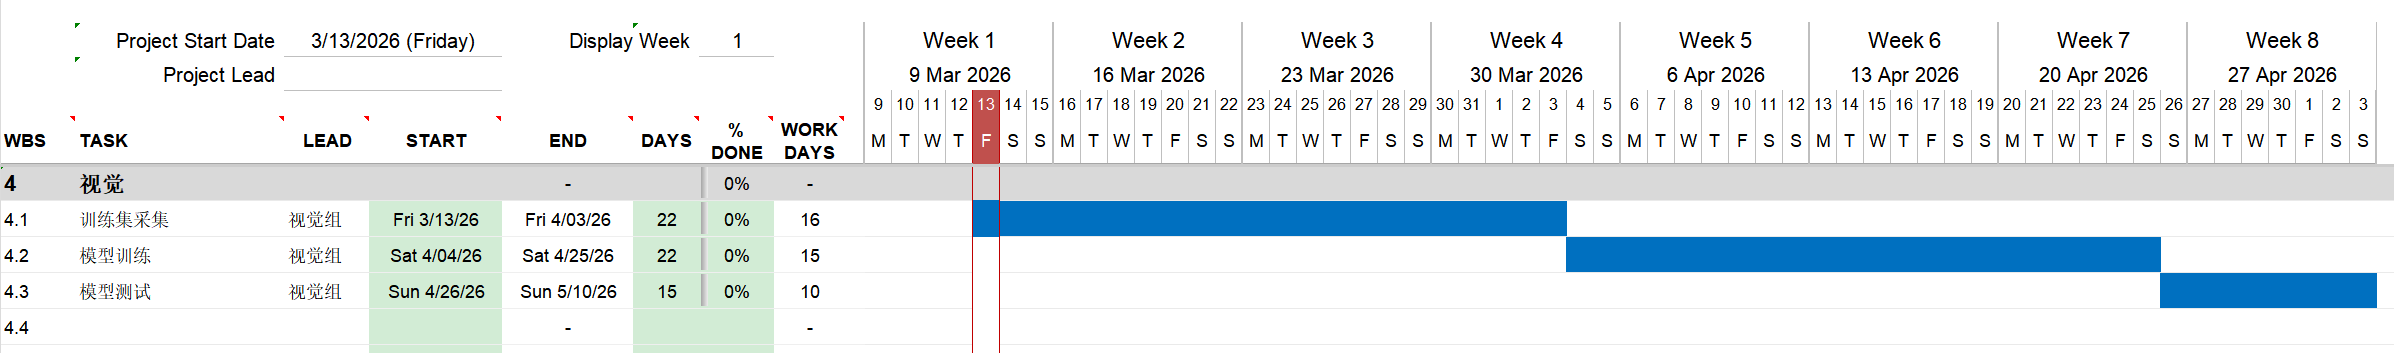
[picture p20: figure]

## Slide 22

Software

AGV upper computer software

We have developed a cross-platform, visual, and user-friendly upper computer software using Python. Below are the modules we employed.

We utilize it to create an elegant GUI interface. The GUI library it provides enabled the implementation of video windows, numerical/string input, and various buttons. It helped us achieve the visualization of the software, significantly reducing the barrier for users to use the AGV.

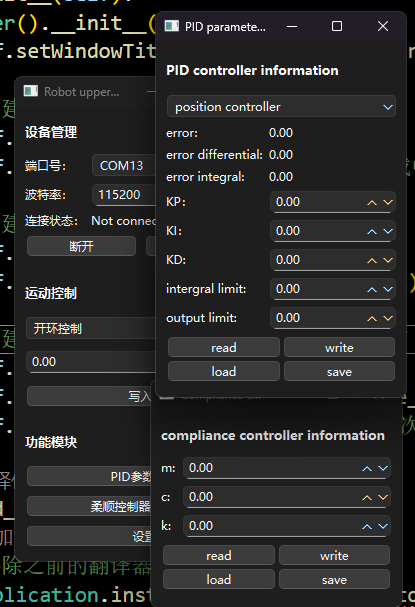
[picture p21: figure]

Pyside6

OpenCV

Pyserial

We utilize it to achieve video stream retrieval and display, and to retain the backend interface for the tracking algorithm for the vision teamer, allowing them to input video and output mask images.

We use it to establish serial communication with the AGV, enabling the issuance of commands and the feedback of information.

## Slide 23

Software

AGV upper computer software

We utilize its Joystick module to implement the input for the game controller, enabling the software to read and process most of the controllers available on the market, making the operation of the AGV more user-friendly. It also utilize its animation library to develop the visualization of the obstacle avoidance system and navigation system, making our software more aesthetically pleasing.

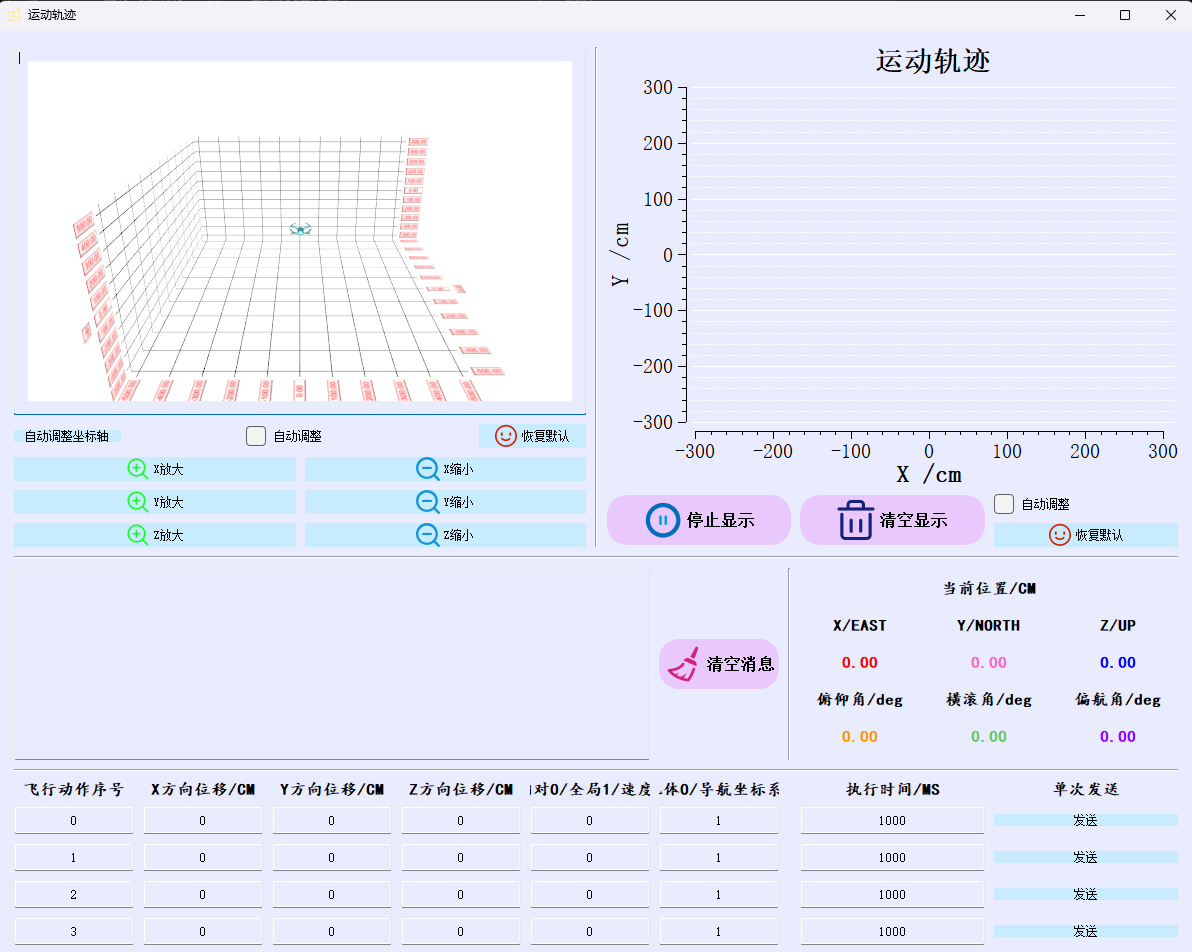
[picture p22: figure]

Pygame

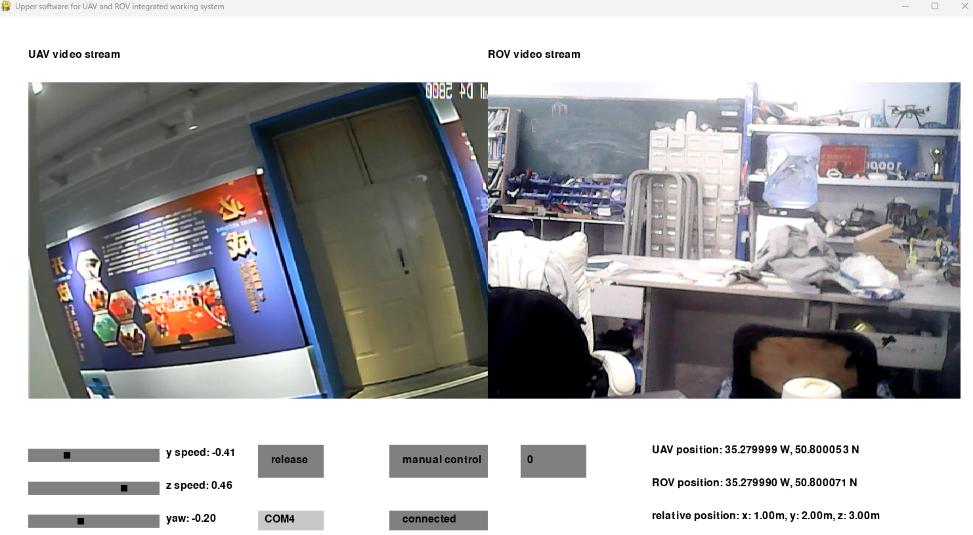
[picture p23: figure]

PyTorch

We have utilize it to incorporate some AI models, such as ultralytics' YOLO26, enabling us to accomplish the task of object detection within the software. In the future, it could even be used as a embodied intelligence platform, further leveraging this module.

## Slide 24

Software

Personal Task Assignment and Progress Schedule

Subtasks | Specific Content
5.1 Backend Design | Develop various backend task modules, such as serial port communication, video stream retrieval, and each module adheres to the principle of low coupling.
2.2 Backend Testing | Test each module independently to ensure that there are no issues with the modules during the later system development process.
2.3 Frontend Design | Design the front-end GUI page, connect the back-end interface, and create a beautiful and elegant software.

Progress Schedule

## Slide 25

Budget Sheet

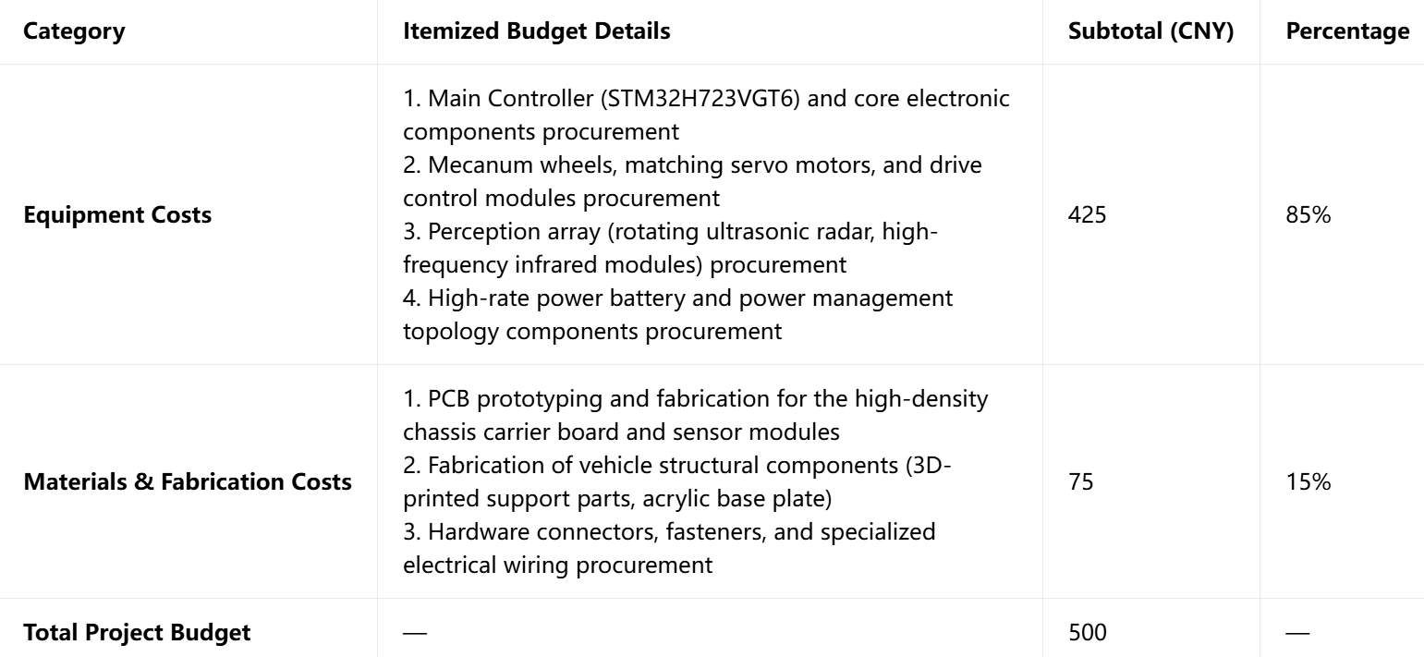
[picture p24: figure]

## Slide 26

This project developed a modular Mecanum-wheeled tracking robot , with its core innovation lying in the high integration of hardware and software. Mechanically, independent suspensions effectively solve the Mecanum wheel vibration issue. For control, we designed a custom high-density motherboard and built low-level algorithms like cascade PID, kinematics, and multitasking scheduling from scratch. Software-wise, a Python-based GUI integrated with the YOLO model enables precise visual perception and obstacle avoidance. The entire system operates stably and is fully controllable.
Looking ahead, we will further expand functions based on this stable platform. We plan to incorporate wireless communication modules to enable more flexible remote control. Furthermore, we will introduce machine learning algorithms for automatic parameter tuning , ultimately upgrading the robot into a powerful embodied intelligence platform.

Summary

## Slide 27

Mecanum-wheeled Autonomous Tracking Robot
Thesis Proposal

Thank you for watching

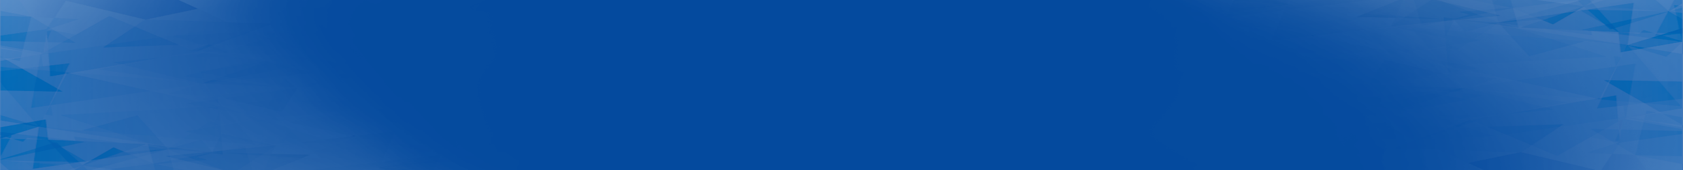
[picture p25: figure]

汇 报 人

姚康晨

汇报日期

2026.3.14

光电材料与器件物理技术研究所 I 半导体物理学与材料研究中心 I 计算机成像技术研究所

Trace Rover Team

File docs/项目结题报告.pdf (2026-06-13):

# Mecanum-wheeled Autonomous Tracking Robot


# Trace Rover Team

## 项目组长 姚康晨

汇报日期 | 2026.5.23
项目成员 | 金振宇 王明睿 赵禺赫 罗子轩

# Contents

01

## Project Overview

Background & Objectives

02

## Structure

Chassis & Scanning Platform

03

## Control

Kinematics, PID & Navigation
04

## Electronic

PCB & Hardware Platform

05

## Software

GUI & Visual Perception

06

## Budget

# Project Overview

## Part One


## Background & Motivation

## Goals & Key Features

In factory environments, safety inspection is essential but repetitive and time-consuming.

Manual inspection may suffer from limited efficiency, blind spots and delayed response.

Growing demand for autonomous robots to monitor industrial environments

# 01 Goals & Key Features

Visual Recognition; Obstacle Avoidance; 360°Omnidirectional Scanning; Autonomous Tracking

Safety Helmet & PPE Detection

• YOLO model for real-time
detection
• Identifies helmet & uniform
compliance

• Stepper motor + timing
belt platform
• Eliminates blind spots in
all directions

Mecanum-Wheel Omni-Drive

• Holonomic motion in any
direction
• Cascade PID closed-loop
control

# Structure

## Part Two

## Chassis Architecture Specifications

## 360° Scanning Platform

## Structural Integration & Key Mechanical Components

# 罗子轩

# 金振宇

# 02 Chassis Architecture Specifications


Double-Layer 3D Structure — Heavy components on bottom layer to lower center of gravity; control board and sensors on top

Vision Mount — Cantilever bracket at front for camera; ensures unobstructed view of workers' PPE status

Load Distribution — Balanced load across 4 Mecanum wheels to prevent slippage

## 罗子轩

# 02 360° Scanning Platform

The Problem

Transmission:
Stepper motor +
timing
belt/pulley —
motor mounted
side to minimise
platform height.

A single fixed ultrasonic
sensor covers only ~55°
forward, leaving over 305°
as blind spots.

# 03 Structural Integration & Key Mechanical Components

## My Work 金振宇

Part drawing:
1. Chassis
2. Camera stand
3. Camera base
4. Chassis housing
5. Shell

Assembly:
1. SW's 3D Assembly
2. Model assembly

# 02 Structural Integration & Key Mechanical Components

## The problem I encountered


Chassis: There are issues of part
interference and size discrepancies
in the red box area.
Solution: Manual polishing
Shell iteration

Camera base: The
issue with the size
of the camera base
is that the rear part
extends too long.
Solution: Manual
polishing

The problem I encountered

1. The shell has undergone three major version iterations.
2. The final version of the casing was adjusted twice regarding the size issue.

# Assembly process


# Electronic

## Part Four

## Schematic Low-Level Optimization Details

## High-Reliability PCB Layout Technology

# 赵禺赫

Deployment with STM32CubeMX; Signal Integrity & Anti-Interference; PCB Design Problems & Optimization

# 04 Schematic Low-Level Optimization Details


Computing Core:
Adopted 550MHz STM32H723VGT6 MCU to support vector control response.

Encoder Protection:
Applied 100nF filter capacitors to shield speed feedback signals from motor interference.

Power Integrity:
Adopted MP1584 DC-DC
converter, equipped with
capacitors to suppress motor ripples.

# 04 High-Reliability PCB Layout Technology


Stitching Via Array:
Arranged stitching vias to lower ground impedance, enhance heat dissipation and restrain noise.

Signal Guarding:
Applied via stitching beside key signals to isolate high-current interference.

Physical Partitioning:
Symmetrical layout separates control and drive zones for strong-weak electricity isolation and EMI reduction.
Top Signal Layer | Bottom Power Layer

# 04 Deployment with STM32CubeMX


550MHz Core Performance:
550MHz clock tree full allocation, full frequency operation.

Unified Peripheral Scheduling: STM32CubeMX allocation of pin functions to generate the source code of Hal Library.

# 04 Signal Integrity & Anti-Interference

PWM Drive Waveform | Bluetooth UART Waveform
Measured Data: Outputs 50.00Hz PWM motion control waveforms. Significance: Fine impedance matching. | Measured Data: Captured low-level digital logic pulses from UART.
| Significance: Signals remain distortion-free.

# 04 PCB Design Problems & Optimization


Problems | Optimization Measures
- Power trace forms closed loop leading to high EMI • Serious heating of circuit board | • Break all power loops by re-routing traces to follow ground plane
| • Add stitching vias along board edges
| • Vias are added on both sides of the signal line

Upgrade

- Signal lines are susceptible to interference

# Control

## Part Three

## MCU System Architecture

## Task Scheduling: Time-Slice Round-Robin

Motor Closed-Loop Control: Cascade PID

## Navigation: Encoder Odometry + Aruco Correction

# 姚康晨

# 03 MCU System Architecture


User APP
Layer 3 — Application
Task scheduling · Motion logic · Communication protocol

HAL
Layer 2 — Hardware Abstraction
Sensor drivers · Encoder feedback · PWM generation

BSP / Peripherals
Layer 1 — Driver
STM32 timers · UART · GPIO low-level control

High cohesion, low coupling — all modules encapsulated
via object-oriented design

1

1000 Hz System Tick

STM32 timer interrupt fires every 5 ms, used as the global timestamp base for all task slots.

2

Non-Blocking Scheduling

Each task runs within its allocated time slice without blocking others — ensures real-time responsiveness.

3

Modular Task Design

Motion control, sensor reading, and communication each run as independent modules — easy to debug and extend.

Single-loop PID balances dynamic response and positioning accuracy

Single-loop PID balances dynamic response and positioning accuracy

# 03 Motor Closed-Loop Control: Cascade PID


Speed feedforward
controller

problem1. The system; response speed is too; slow.; 2. The motor is; experiencing severe; vibration.; 3. The braking speed; is too slow.; solution; 1. Apply the; feedforward controller.; 2. Apply the output; smoothing algorithm.; 3. Apply the integral; anti-saturation; algorithm

## Inertial navigation system based on encoder

To obtain the position and speed information of the
car as feedback values for closed-loop control, we
used the encoder on the motor to implement an incremental odometry inertial navigation system.


This system operates stably at a frequency of 200Hz, but the error accumulation caused by slippage and noise is unacceptable.

Therefore, our vision group and software group implemented its aruco code navigation system, solving the drift problem of inertial navigation.

# 03 Navigation: Encoder Odometry + Aruco Correction

# Software

## Part Five

## Communication Module

## Upper Computer Software

## Navigation Visualization & Mission Planner

## Vision Process: YOLO Detection & Aruco Navigation

# 王明睿

## Stable Communication

# 05 Communication Module


As we adopted the Bluetooth module as the communication method, in order to achieve BLE protocol communication between the upper computer and the lower computer, we applied the bleak library and, based on the data frame format we defined, developed the communication module. This module serves as the foundation for the upper computer to control and monitor the AGV.


## AGV upper computer software

We have developed a cross-platform, visual, and user-friendly upper computer control software using PySide6.

The four core modules are placed in five separate windows and are controlled by a main window.

In the motion control interface, users can manually input control values in the interface and send them. We also use the joystick module in Pygame to allow users to control the AGV with a gamepad.

In the parameter tuning interface, users can input PID parameters in the interface and send them to the AGV, read parameters from the AGV, and load or save parameters from a local JSON file on the computer.

## Navigation information visionalizition

We used QtGraph to plot the
movement trajectory, speed
curve and radar image of the
AGV, enabling users to
visually observe the navigation status of the AGV.

# 05 Navigation Visualization & Mission Planner


### Mission planner

In order to ensure that the AGV can complete the automatic cruise operation, we have developed a mission planner for the AGV, which can control the vehicle to automatically complete the cruise task.
We have developed a simple and intuitive operation interface using QTableWidget, which can read, edit and save the original json task code. Users do not need to understand the original code. They can complete the programming for the car task simply by following the instructions on the interface.

# 05 Navigation Visualization & Mission Planner

## AGV vision process

In the software, we use
OpenCV to read the
transmitted images and allow users to activate the YOLO26 model for recognition, as well as utilize the function of using Aruco codes for navigation correction.


# Vision

## Part Six

## YOLO Model: Dataset & Training Pipeline

## ArUco Code Positioning & Drift Correction

# 姚康晨

## YOLO26 model training

# 06 YOLO Model: Dataset & Training Pipeline

In order to complete the recognition of safety helmets, we collected and labeled the training set ourselves, and used the small-scale model of YOLO26 to complete the training on the server.

## ArUco code positioning

# 06 ArUco Code Positioning & Drift Correction


Because the built-in inertial navigation system of the car is prone to drift in terms of integration due to factors such as skidding, missing steps and oscillation, it is necessary to pre-arrange ArUco codes on the track and use its camera for calibration and positioning.

# 07 Budget


# Mecanum-wheeled Autonomous Tracking Robot


### 光电材料与器件物理技术研究所 I 半导体物理学与材料研究中心 I 计算机成像技术研究所

# Thank you for watching

汇 报 人 | 姚康晨
汇报日期 | 2026.5.23

# Trace Rover Team

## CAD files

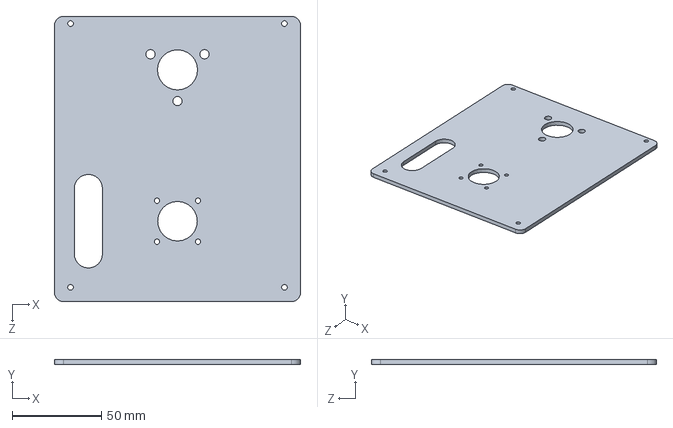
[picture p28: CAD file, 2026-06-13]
structure/上层板绘制尝试.SLDPRT
138.0 x 3.00 x 160.0 mm

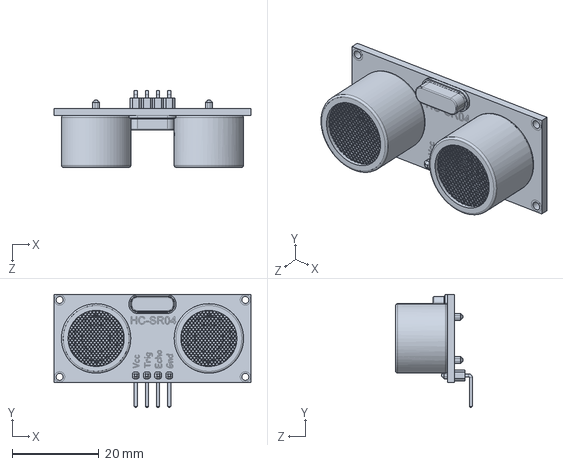
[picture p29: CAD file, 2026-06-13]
structure/Sensor Ultrasónico.SLDPRT
45.4 x 26.1 x 17.7 mm

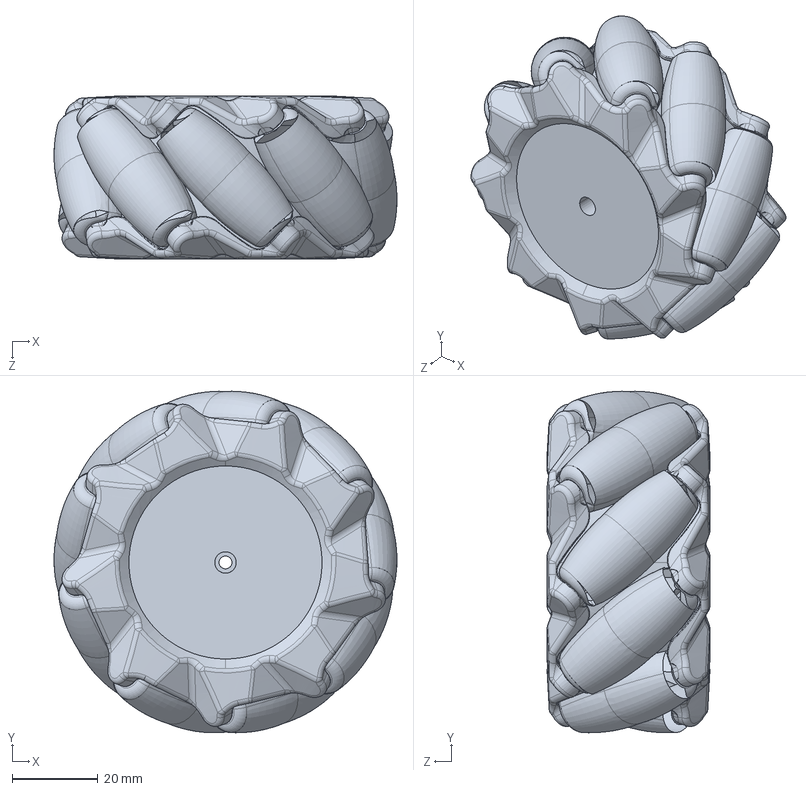
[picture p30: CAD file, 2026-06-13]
structure/80r.2.SLDPRT
80.0 x 79.6 x 37.9 mm

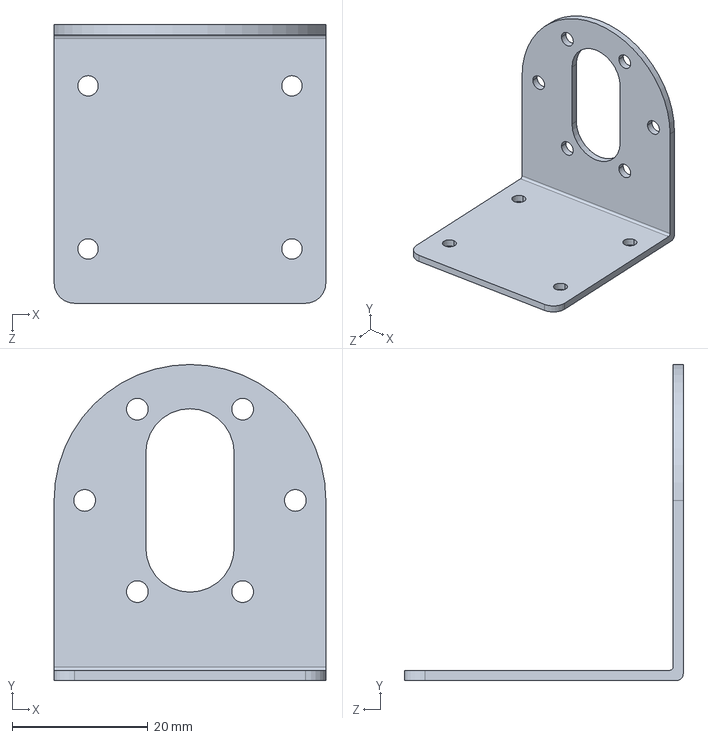
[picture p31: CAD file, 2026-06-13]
structure/37电机支架.step.SLDPRT
40.0 x 46.5 x 41.0 mm

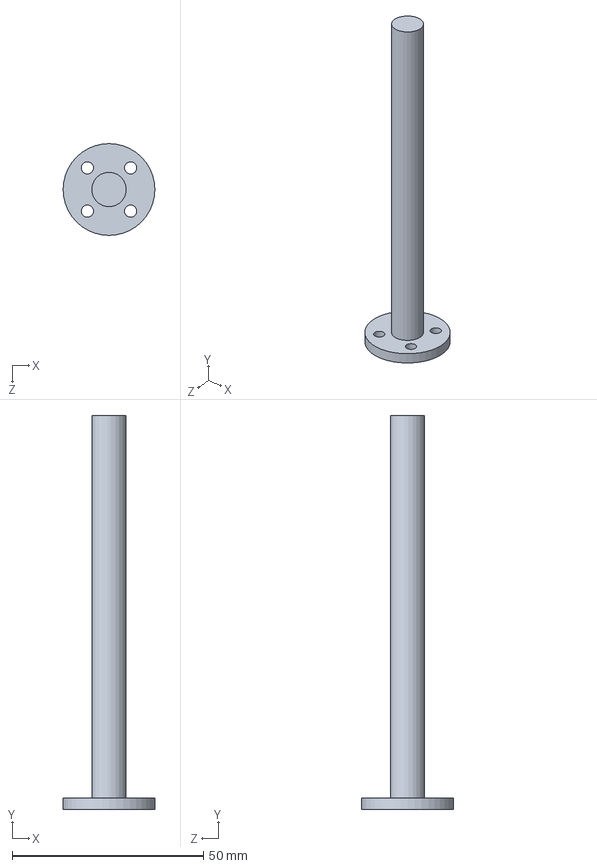
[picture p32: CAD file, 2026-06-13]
structure/相机柱.SLDPRT
24.0 x 103.0 x 24.0 mm

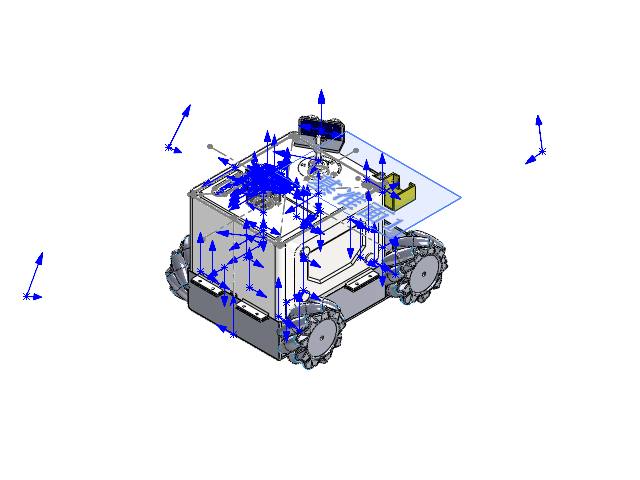
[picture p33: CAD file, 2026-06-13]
structure/（模型装配体）.SLDASM
底盘模型
37电机支架.step x 4
MC520编码器电机模型-升级款.step x 4
图传发射模块
80r.2 x 2
80l.2 x 2
电池
ts-1145a-b-a_White.step.STEP x 2
PH2.0-WI-____.step.STEP x 4
PH2.0-WI-4P-0.step.STEP
PH2.0-WI-____-1.step.STEP x 8
PH2.0-WI-8P-3.step.STEP
Extruded.step.STEP
Extruded-4.step.STEP
28_STEPPER_MOTOR.STEP
SHIM_2.7x4x6.STEP x 4
ZDT_X28_V1.2.STEP
M2.5x9mm_Phillips.STEP x 4
WIRE_2.0.STEP
BREACKET
HTPA20S5M100_A_P6_35_a - 电机侧
HTPA20S5M100_A_P6_35_a_导电滑环侧
MT0522..FL
Sensor Ultrasónico
电机联轴器
电机延长轴
滑环轴
上层板绘制尝试
皮带1-1
支柱 x 4
PCB支柱 x 4
相机柱80mm
相机底座
MG90S 舵机
外壳终版
小车底盘壳

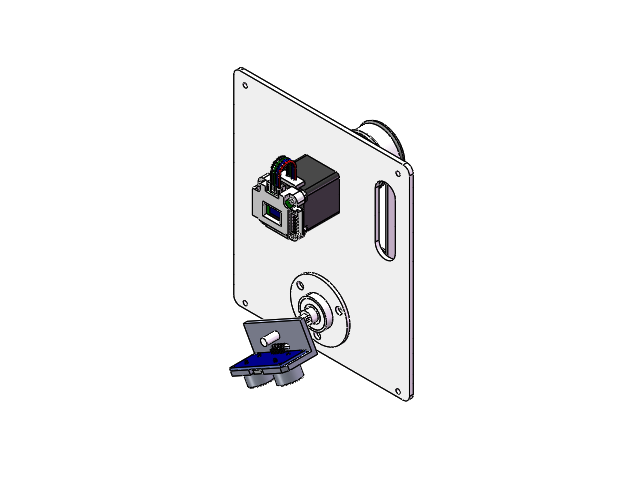
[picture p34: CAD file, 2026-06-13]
structure/上层装配1.SLDASM
ts-1145a-b-a_White.step.STEP x 2
PH2.0-WI-____.step.STEP x 4
PH2.0-WI-4P-0.step.STEP
PH2.0-WI-____-1.step.STEP x 8
PH2.0-WI-8P-3.step.STEP
Extruded.step.STEP
Extruded-4.step.STEP
28_STEPPER_MOTOR.STEP
SHIM_2.7x4x6.STEP x 4
ZDT_X28_V1.2.STEP
M2.5x9mm_Phillips.STEP x 4
WIRE_2.0.STEP
BREACKET
HTPA20S5M100_A_P6_35_a - 电机侧
HTPA20S5M100_A_P6_35_a_导电滑环侧
MT0522..FL
Sensor Ultrasónico
电机联轴器
电机延长轴
滑环轴
上层板绘制尝试

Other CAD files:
structure/PH2.0-WI-8P.step.STEP.SLDASM
structure/J6.step.STEP.SLDASM
structure/PH2.0-WI-4P.step.STEP.SLDASM
structure/J1.step.STEP.SLDASM
structure/Board.step.STEP.SLDASM
structure/Enter.step.STEP.SLDASM
structure/Next.step.STEP.SLDASM
structure/ZDT_X28_L28Motor.STEP.SLDASM
structure/J3.step.STEP.SLDASM
structure/ZDT_X28_V1.2_PCB.step.STEP.SLDASM
structure/Open CASCADE STEP translator 6.8 1.1.1.step.STEP.SLDPRT
structure/28_STEPPER_MOTOR.STEP.SLDPRT
structure/6308926832.step.STEP.SLDASM
structure/6308926992.step.STEP.SLDASM
structure/80l.2.SLDPRT
structure/80l.SLDPRT
structure/80r.SLDPRT
structure/BREACKET.SLDPRT
structure/Extruded-4.step.STEP.SLDPRT
structure/Extruded.step.STEP.SLDPRT
structure/HTPA20S5M100_A_P6_35_a - 电机侧.SLDPRT
structure/HTPA20S5M100_A_P6_35_a_导电滑环侧.SLDPRT
structure/M2.5x9mm_Phillips.STEP.SLDPRT
structure/MC520编码器电机模型-升级款.step.SLDPRT
structure/MT0522..FL.SLDPRT
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

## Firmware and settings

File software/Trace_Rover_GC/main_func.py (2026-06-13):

# -*- coding: utf-8 -*-
from PySide6.QtWidgets import QWidget, QMessageBox
from PySide6.QtCore import Qt, Signal
from main_widget import Ui_Form as MainUiForm
from trace_rover_comm import trace_rover
from control import NewControlWidget
from pid import NewPidWidget
from navigation import StateMonitorWidget
from vision import VisionWidget
from mission import MissionWidget
from config import MAC_ADDRESS

class NewMainWidget(QWidget):
    # 定义信号：设备连接状态变化
    conn_state_changed = Signal(bool, trace_rover)

    def __init__(self, parent=None):
        super().__init__(parent)
        self.ui = MainUiForm()
        self.ui.setupUi(self)
        self.setWindowTitle("Trace Rover Ground Control Software")
        self.ui.mac_line.setText(MAC_ADDRESS)

        # 初始化子窗口实例（单例）
        self.control_widget = None
        self.pid_widget = None
        self.state_widget = None
        self.vision_widget = None
        self.mission_widget = None

        # 小车通信实例
        self.rover = None
        self.is_connected = False

        # 初始化控件
        self._init_widgets()

    def _init_widgets(self):
        """初始化控件逻辑"""
        # 设备连接/断开按钮
        self.ui.connect_button.clicked.connect(self._on_connect)
        self.ui.disconnect_button.clicked.connect(self._on_disconnect)
        self.ui.disconnect_button.setEnabled(False)

        # 功能模块按钮
        self.ui.control_button.clicked.connect(self._open_control_widget)
        self.ui.vision_button.clicked.connect(self._open_vision_widget)
        self.ui.navigation_button.clicked.connect(self._open_state_widget)
        self.ui.pid_button.clicked.connect(self._open_pid_widget)
        self.ui.mission_button.clicked.connect(self._open_mission_widget)

        # 初始状态
        self.ui.connect_state.setText("unconnected")

    def _on_connect(self):
        """连接小车"""
        mac_addr = self.ui.mac_line.text().strip()
        if not mac_addr:
            QMessageBox.warning(self, "Warning", "Please select or input MAC address!")
            return

        try:
            self.rover = trace_rover(mac_addr)
            self.is_connected = True
            self.ui.connect_state.setText("connected")
            self.ui.connect_button.setEnabled(False)
            self.ui.disconnect_button.setEnabled(True)
            self.conn_state_changed.emit(True, self.rover)
            QMessageBox.information(self, "Success", f"Connected to: {mac_addr}")
        except Exception as e:
            QMessageBox.critical(self, "Error", f"Connection failed: {str(e)}")

    def _on_disconnect(self):
        """断开连接"""
        if self.rover:
            self.rover.close()
            self.rover = None
        self.is_connected = False
        self.ui.connect_state.setText("unconnected")
        self.ui.connect_button.setEnabled(True)
        self.ui.disconnect_button.setEnabled(False)
        self.conn_state_changed.emit(False, None)

        # 关闭所有子窗口
        self._close_all_sub_widgets()

    def _open_control_widget(self):
        """打开运动控制窗口（单例）"""
        if not self.is_connected:
            QMessageBox.warning(self, "Warning", "Please connect to the rover first!")
            return
        if not self.control_widget:
            self.control_widget = NewControlWidget(self.rover, None)
            self.control_widget.close_signal.connect(lambda: setattr(self, "control_widget", None))
        self.control_widget.show()
        self.control_widget.raise_()

    def _open_vision_widget(self):
        """打开视觉识别窗口（单例）"""
        if not self.is_connected:
            QMessageBox.warning(self, "Warning", "Please connect to the rover first!")
            return
        if not self.vision_widget:
            self.vision_widget = VisionWidget(self.rover, None)
            self.vision_widget.close_signal.connect(lambda: setattr(self, "vision_widget", None))
        self.vision_widget.show()
        self.vision_widget.raise_()

    def _open_state_widget(self):
        """打开状态监控窗口（单例）"""
        if not self.is_connected:
            QMessageBox.warning(self, "Warning", "Please connect to the rover first!")
            return
        if not self.state_widget:
            self.state_widget = StateMonitorWidget(self.rover, None)
            self.state_widget.close_signal.connect(lambda: setattr(self, "state_widget", None))
        self.state_widget.show()
        self.state_widget.raise_()

    def _open_pid_widget(self):
        """打开PID调参窗口（单例）"""
        if not self.is_connected:
            QMessageBox.warning(self, "Warning", "Please connect to the rover first!")
            return
        if not self.pid_widget:
            self.pid_widget = NewPidWidget(self.rover, None)
            self.pid_widget.close_signal.connect(lambda: setattr(self, "pid_widget", None))
        self.pid_widget.show()
        self.pid_widget.raise_()

    def _open_mission_widget(self):
        """打开任务规划窗口（单例）"""
        if not self.mission_widget:
            self.mission_widget = MissionWidget(self.rover, None)
            self.mission_widget.close_signal.connect(lambda: setattr(self, "mission_widget", None))
        self.mission_widget.show()
        self.mission_widget.raise_()

    def _close_all_sub_widgets(self):
        """关闭所有子窗口"""
        for widget in [self.control_widget, self.pid_widget, self.state_widget, self.vision_widget, self.mission_widget]:
            if widget:
                widget.close()

    def closeEvent(self, event):
        """关闭主窗口时清理资源"""
        self._on_disconnect()
        event.accept()
        
'''__||_____||__
   __||_____||__
   ___\\___//___
   _===========_
   _____|||_____
   _____|||_____
   ______|______
   ___防伪专用___'''

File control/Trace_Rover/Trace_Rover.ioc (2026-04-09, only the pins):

Mcu.UserName=STM32H723VGTx
PA0.Signal=S_TIM2_CH1_ETR
PA1.Signal=S_TIM2_CH2
PA13(JTMS/SWDIO).Signal=DEBUG_JTMS-SWDIO
PA14(JTCK/SWCLK).Signal=DEBUG_JTCK-SWCLK
PA2.Signal=S_TIM5_CH3
PA3.Signal=GPIO_Output
PA4.Signal=GPIO_Output
PA6.Signal=S_TIM3_CH1
PA7.Signal=S_TIM3_CH2
PA8.Signal=S_TIM1_CH1
PA9.Signal=S_TIM1_CH2
PB10.Signal=USART3_TX
PB11.Signal=USART3_RX
PB14.Signal=USART1_TX
PB15.Signal=USART1_RX
PC6.Signal=S_TIM8_CH1
PC7.Signal=S_TIM8_CH2
PD0.Signal=GPIO_Output
PD1.Signal=GPIO_Output
PD10.Signal=GPIO_Output
PD11.Signal=GPIO_Output
PD12.Signal=S_TIM4_CH1
PD13.Signal=S_TIM4_CH2
PD14.Signal=S_TIM4_CH3
PD15.Signal=S_TIM4_CH4
PD2.Signal=GPIO_Output
PD3.Signal=GPIO_Output
PD5.Signal=USART2_TX
PD6.Signal=USART2_RX
PD8.Signal=GPIO_Output
PD9.Signal=GPIO_Output
PE5.Signal=S_TIM15_CH1
PH0-OSC_IN.Signal=RCC_OSC_IN
PH1-OSC_OUT.Signal=RCC_OSC_OUT

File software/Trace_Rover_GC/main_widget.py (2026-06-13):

# -*- coding: utf-8 -*-

################################################################################
## Form generated from reading UI file 'main_widget.ui'
##
## Created by: Qt User Interface Compiler version 6.9.2
##
## WARNING! All changes made in this file will be lost when recompiling UI file!
################################################################################

from PySide6.QtCore import (QCoreApplication, QDate, QDateTime, QLocale,
    QMetaObject, QObject, QPoint, QRect,
    QSize, QTime, QUrl, Qt)
from PySide6.QtGui import (QBrush, QColor, QConicalGradient, QCursor,
    QFont, QFontDatabase, QGradient, QIcon,
    QImage, QKeySequence, QLinearGradient, QPainter,
    QPalette, QPixmap, QRadialGradient, QTransform)
from PySide6.QtWidgets import (QApplication, QFormLayout, QHBoxLayout, QLabel,
    QLineEdit, QPushButton, QSizePolicy, QVBoxLayout,
    QWidget)

class Ui_Form(object):
    def setupUi(self, Form):
        if not Form.objectName():
            Form.setObjectName(u"Form")
        Form.resize(251, 366)
        Form.setMinimumSize(QSize(251, 366))
        Form.setSizeIncrement(QSize(0, 0))
        Form.setBaseSize(QSize(251, 454))
        self.verticalLayoutWidget_2 = QWidget(Form)
        self.verticalLayoutWidget_2.setObjectName(u"verticalLayoutWidget_2")
        self.verticalLayoutWidget_2.setGeometry(QRect(10, 170, 231, 181))
        self.verticalLayout_1 = QVBoxLayout(self.verticalLayoutWidget_2)
        self.verticalLayout_1.setObjectName(u"verticalLayout_1")
        self.verticalLayout_1.setContentsMargins(0, 0, 0, 0)
        self.mod_label = QLabel(self.verticalLayoutWidget_2)
        self.mod_label.setObjectName(u"mod_label")
        font = QFont()
        font.setPointSize(10)
        font.setBold(True)
        self.mod_label.setFont(font)

        self.verticalLayout_1.addWidget(self.mod_label)

        self.control_button = QPushButton(self.verticalLayoutWidget_2)
        self.control_button.setObjectName(u"control_button")

        self.verticalLayout_1.addWidget(self.control_button)

        self.vision_button = QPushButton(self.verticalLayoutWidget_2)
        self.vision_button.setObjectName(u"vision_button")

        self.verticalLayout_1.addWidget(self.vision_button)

        self.navigation_button = QPushButton(self.verticalLayoutWidget_2)
        self.navigation_button.setObjectName(u"navigation_button")

        self.verticalLayout_1.addWidget(self.navigation_button)

        self.pid_button = QPushButton(self.verticalLayoutWidget_2)
        self.pid_button.setObjectName(u"pid_button")

        self.verticalLayout_1.addWidget(self.pid_button)

        self.mission_button = QPushButton(self.verticalLayoutWidget_2)
        self.mission_button.setObjectName(u"mission_button")

        self.verticalLayout_1.addWidget(self.mission_button)

        self.verticalLayoutWidget_3 = QWidget(Form)
        self.verticalLayoutWidget_3.setObjectName(u"verticalLayoutWidget_3")
        self.verticalLayoutWidget_3.setGeometry(QRect(10, 10, 231, 145))
        self.verticalLayout_2 = QVBoxLayout(self.verticalLayoutWidget_3)
        self.verticalLayout_2.setObjectName(u"verticalLayout_2")
        self.verticalLayout_2.setContentsMargins(0, 0, 0, 0)
        self.device_label = QLabel(self.verticalLayoutWidget_3)
        self.device_label.setObjectName(u"device_label")
        self.device_label.setFont(font)

        self.verticalLayout_2.addWidget(self.device_label)

        self.formLayout = QFormLayout()
        self.formLayout.setObjectName(u"formLayout")
        self.mac_label = QLabel(self.verticalLayoutWidget_3)
        self.mac_label.setObjectName(u"mac_label")

        self.formLayout.setWidget(0, QFormLayout.ItemRole.LabelRole, self.mac_label)

        self.state_label = QLabel(self.verticalLayoutWidget_3)
        self.state_label.setObjectName(u"state_label")

        self.formLayout.setWidget(1, QFormLayout.ItemRole.LabelRole, self.state_label)

        self.connect_state = QLabel(self.verticalLayoutWidget_3)
        self.connect_state.setObjectName(u"connect_state")

        self.formLayout.setWidget(1, QFormLayout.ItemRole.FieldRole, self.connect_state)

        self.mac_line = QLineEdit(self.verticalLayoutWidget_3)
        self.mac_line.setObjectName(u"mac_line")

        self.formLayout.setWidget(0, QFormLayout.ItemRole.FieldRole, self.mac_line)


        self.verticalLayout_2.addLayout(self.formLayout)

        self.horizontalLayout_2 = QHBoxLayout()
        self.horizontalLayout_2.setObjectName(u"horizontalLayout_2")
        self.disconnect_button = QPushButton(self.verticalLayoutWidget_3)
        self.disconnect_button.setObjectName(u"disconnect_button")

        self.horizontalLayout_2.addWidget(self.disconnect_button)

        self.connect_button = QPushButton(self.verticalLayoutWidget_3)
        self.connect_button.setObjectName(u"connect_button")

        self.horizontalLayout_2.addWidget(self.connect_button)


        self.verticalLayout_2.addLayout(self.horizontalLayout_2)


        self.retranslateUi(Form)

        QMetaObject.connectSlotsByName(Form)
    # setupUi

    def retranslateUi(self, Form):
        Form.setWindowTitle(QCoreApplication.translate("Form", u"Form", None))
        self.mod_label.setText(QCoreApplication.translate("Form", u"function module", None))
        self.control_button.setText(QCoreApplication.translate("Form", u"motion controll", None))
        self.vision_button.setText(QCoreApplication.translate("Form", u"video stream", None))
        self.navigation_button.setText(QCoreApplication.translate("Form", u"navigation information", None))
        self.pid_button.setText(QCoreApplication.translate("Form", u"PID parameter tuning", None))
        self.mission_button.setText(QCoreApplication.translate("Form", u"mission planning", None))
        self.device_label.setText(QCoreApplication.translate("Form", u"device management", None))
        self.mac_label.setText(QCoreApplication.translate("Form", u"MAC:", None))
        self.state_label.setText(QCoreApplication.translate("Form", u"connection:", None))
        self.connect_state.setText(QCoreApplication.translate("Form", u"unconnected", None))
        self.disconnect_button.setText(QCoreApplication.translate("Form", u"disconnect", None))
        self.connect_button.setText(QCoreApplication.translate("Form", u"connect", None))
    # retranslateUi

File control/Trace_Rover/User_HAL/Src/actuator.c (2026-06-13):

/**
 * @file actuator.c
 * @author 姚康晨 (2134374074@qq.com)
 * @brief STM32平台执行器的C语言抽象(针对带编码器的两相直流电机)
 * @version 0.1
 * @date 2026-03-30
 *
 * @copyright Copyright (c) 2026
 *
 */

#include "actuator.h"

/**
 * @brief 初始化直流电机
 * 
 * @param motor 直流电机指针
 * @param htim 定时器句柄
 * @param channel 定时器通道
 * @param enc_htim 编码器定时器句柄
 * @param gpio_port_1 GPIO端口1
 * @param gpio_pin_1 GPIO引脚1
 * @param gpio_port_2 GPIO端口2
 * @param gpio_pin_2 GPIO引脚2
 * @param v_pid 速度PID控制器指针
 * @param p_pid 位置PID控制器指针
 */
void motor_init(dc_motor *motor, TIM_HandleTypeDef *htim, uint32_t channel, 
    TIM_HandleTypeDef *enc_htim, GPIO_TypeDef *gpio_port_1, uint16_t gpio_pin_1, 
    GPIO_TypeDef *gpio_port_2, uint16_t gpio_pin_2, dc_motor_dir dir,
    pid *v_pid, pid *p_pid) {
    
    motor->htim = htim;
    motor->channel = channel;
    motor->enc_htim = enc_htim;
    motor->dir = dir;
    if(dir == CW) {
        motor->gpio_port_1 = gpio_port_2;
        motor->gpio_pin_1 = gpio_pin_2;
        motor->gpio_port_2 = gpio_port_1;
        motor->gpio_pin_2 = gpio_pin_1;
    } else {
        motor->gpio_port_1 = gpio_port_1;
        motor->gpio_pin_1 = gpio_pin_1;
        motor->gpio_port_2 = gpio_port_2;
        motor->gpio_pin_2 = gpio_pin_2;
    }
    
    motor->v_pid = *v_pid;
    motor->p_pid = *p_pid;

    // 初始化pwm定时器
    HAL_TIM_PWM_Start(motor->htim, motor->channel);

    // 初始化编码器定时器
    HAL_TIM_Encoder_Start(motor->enc_htim, TIM_CHANNEL_ALL);

    motor->last_time = HAL_GetTick();
}

/**
 * @brief 输出直流电机的PWM占空比
 * 
 * @param motor 直流电机指针
 * @param input 输入值，范围为-1到1，对应电机转速的正负和大小
 */
void motor_output(dc_motor *motor, float input) {
    // 输入为-1到1之间的值，对应电机转速的正负和大小
    // 限制输出范围
    input = fmax(input, -MOTOR_PWM_MAX);
    input = fmin(input, MOTOR_PWM_MAX);
    // 死区处理
    if(fabs(input) < MOTOR_OUTPUT_DEADBAND) {
        input = 0.0f;
    }
    // 限制输出斜率
        if(fabs(input - motor->last_output) > MOTOR_OUTPUT_GRADIENT) 
    {
        input = motor->last_output + (input > motor->last_output ? MOTOR_OUTPUT_GRADIENT : -MOTOR_OUTPUT_GRADIENT);
    }
    motor->last_output = input;
    uint16_t pwm_value = (uint16_t)(fabs(input) * MOTOR_PWM_MAX);
    // 设置PWM占空比
    HAL_GPIO_WritePin(motor->gpio_port_1, motor->gpio_pin_1, input >= 0 ? GPIO_PIN_SET : GPIO_PIN_RESET);
    HAL_GPIO_WritePin(motor->gpio_port_2, motor->gpio_pin_2, input >= 0 ? GPIO_PIN_RESET : GPIO_PIN_SET);

    __HAL_TIM_SET_COMPARE(motor->htim, motor->channel, pwm_value);
}

/**
 * @brief 设置直流电机的状态
 * 
 * @param motor 直流电机指针
 * @param state 直流电机状态
 */
void motor_set_state(dc_motor *motor, dc_motor_state state) {
    // 状态切换时重置PID控制器
    pid_reset(&motor->v_pid);
    pid_reset(&motor->p_pid);
    motor->state = state;
}

/**
 * @brief 更新直流电机的状态
 * 
 * @param motor 直流电机指针
 * @param input 输入值
 */
void motor_update(dc_motor *motor, float input) {
    // 读取编码器计数
    int16_t encoder_count = (int16_t)__HAL_TIM_GET_COUNTER(motor->enc_htim);    // 强制将32位寄存器和16位寄存器统一成int16_t
    float delta_position = (encoder_count / ENCODER_PPR) * (2 * 3.1415926535f * TIRE_RADIUS) / ENCODER_GEAR_RATIO;
    __HAL_TIM_SET_COUNTER(motor->enc_htim, 0); // 重置编码器计数

    // 计算当前速度和位置
    if(motor->dir == CW) {
        motor->real_position += delta_position;
    } else {
        motor->real_position -= delta_position;
    }
    
    uint32_t current_time = HAL_GetTick();
    if(motor->dir == CW) {
        motor->real_speed = delta_position / ((current_time - motor->last_time) / 1000.0f);
    } else {
        motor->real_speed = -delta_position / ((current_time - motor->last_time) / 1000.0f);
    }
    motor->last_time = current_time;
    float output;
	float speed_error;
    float feedforward = motor->target_speed; // 前馈项，直接使用目标速度作为前馈输出

    switch (motor->state)
    {
    case OPEN_LOOP:
        // 开环控制
        motor_output(motor, input);
        break;
    case SPEED_LOOP:
        // 速度环控制
        motor->target_speed = input;
        speed_error = motor->target_speed - motor->real_speed;
        pid_refresh(&motor->v_pid, speed_error);
        output = motor->v_pid.output + feedforward;
		motor_output(motor, output);
        break;
    case POSITION_LOOP:
        // 串级控制
        // 外环：位置环
        motor->target_position = input;
        float position_error = motor->target_position;
        pid_refresh(&motor->p_pid, position_error);
        // 内环：速度环
        motor->target_speed = motor->p_pid.output;
        speed_error = motor->target_speed - motor->real_speed;
        pid_refresh(&motor->v_pid, speed_error);
        output = motor->v_pid.output + feedforward;
		motor_output(motor, output);
        break;
    
    default:
        break;
    }
}

/**
 * @brief 初始化180度舵机
 * 
 * @param servo 180度舵机指针
 * @param htim 定时器句柄
 * @param channel 定时器通道
 */
void servo_180_init(servo_180 *servo, TIM_HandleTypeDef *htim, uint32_t channel) {
    servo->htim = htim;
    servo->channel = channel;
    HAL_TIM_PWM_Start(servo->htim, servo->channel);
}

/**
 * @brief 设置180度舵机的角度
 * 
 * @param servo 180度舵机指针
 * @param angle 角度值，范围为0到180度
 */
void servo_180_set_angle(servo_180 *servo, float angle) {
    // 限制角度范围
    angle = fmax(angle, 0.0f);
    angle = fmin(angle, 180.0f);
    // 将角度转换为PWM占空比
    uint16_t pwm_value = (uint16_t)((angle / 180.0f) * SERVO_PWM_MAX + SERVO_PWM_MIN);
    __HAL_TIM_SET_COMPARE(servo->htim, servo->channel, pwm_value);
}



/*__||_____||__
  __||_____||__
  ___\\___//___
  _===========_
  _____|||_____
  _____|||_____
  ______|______
  ___防伪专用___*/

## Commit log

2026-03-22 feat: 添加相机标定、ArUco 码生成及检测功能，上传相关图片和参数文件
2026-03-27 feat: 添加安全帽检查模型，单片机工程，PCB工程
2026-04-01 feat: 开始编写小车导航与控制算法
2026-04-06 feat: 完成小车通信模块编写
    [Emm28_V5外壳.STL, Emm35_V5外壳.STL, Emm42_V5注塑外壳.STL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]
2026-04-09 feat: 下位机程序完成，上位机通信完成，开始调试
    [通信协议.xlsx]
2026-04-10 feat: 修正电机转动方向的bug，开始调试闭环控制
    [通信协议.xlsx]
2026-04-11 feat: 底盘闭环调试完成
2026-04-11 feat: 里程计惯导修复成功，闭环算法优化完成
2026-04-13 feat: 搭建上位机软件框架
    [config_pid.json]
2026-04-17 feat: 完善上位机视觉窗口
2026-04-19 feat: 完善上位机导航窗口
    [config_pid.json]
2026-06-13 feat: 发布正式版
    [28_STEPPER_MOTOR.STEP.SLDPRT, 37电机支架.step.SLDPRT, 6308926832.step.STEP.SLDASM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]
2026-06-27 feat: 完成项目报告编写
